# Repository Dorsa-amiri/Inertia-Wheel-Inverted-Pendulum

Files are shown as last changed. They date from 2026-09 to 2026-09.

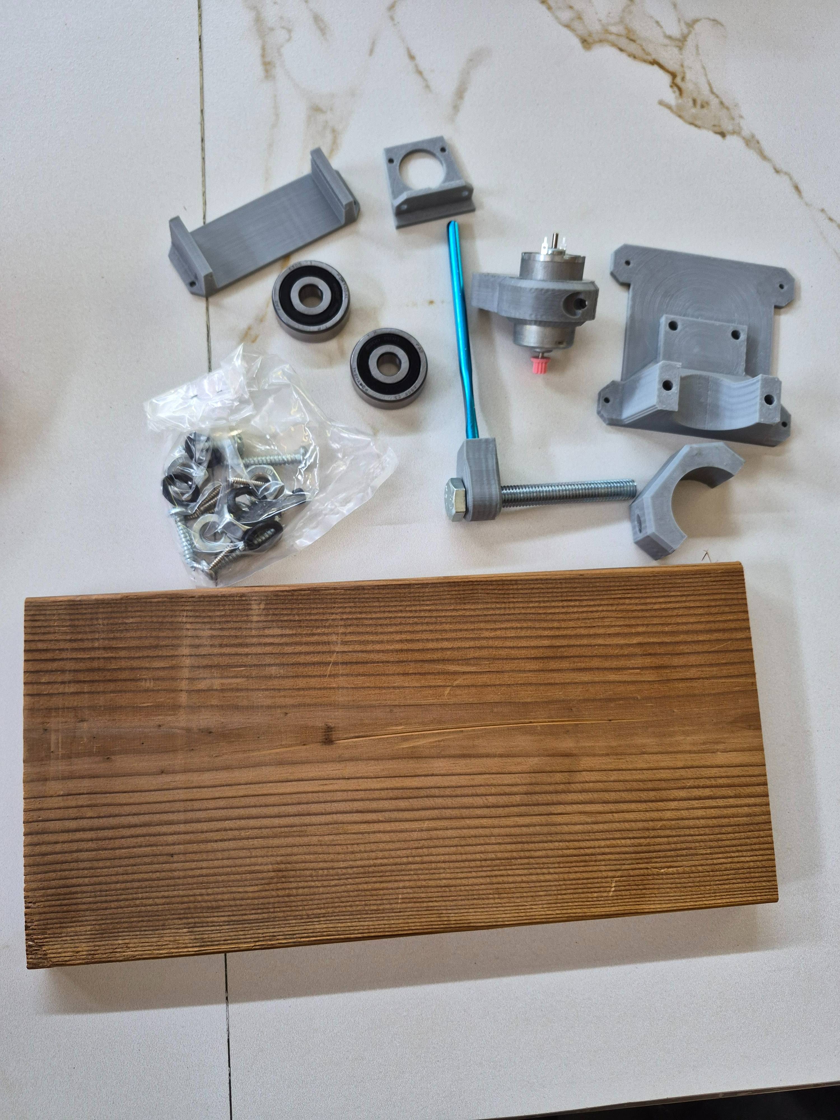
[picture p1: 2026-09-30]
Images/Components/20260816_130111_compressed.jpg

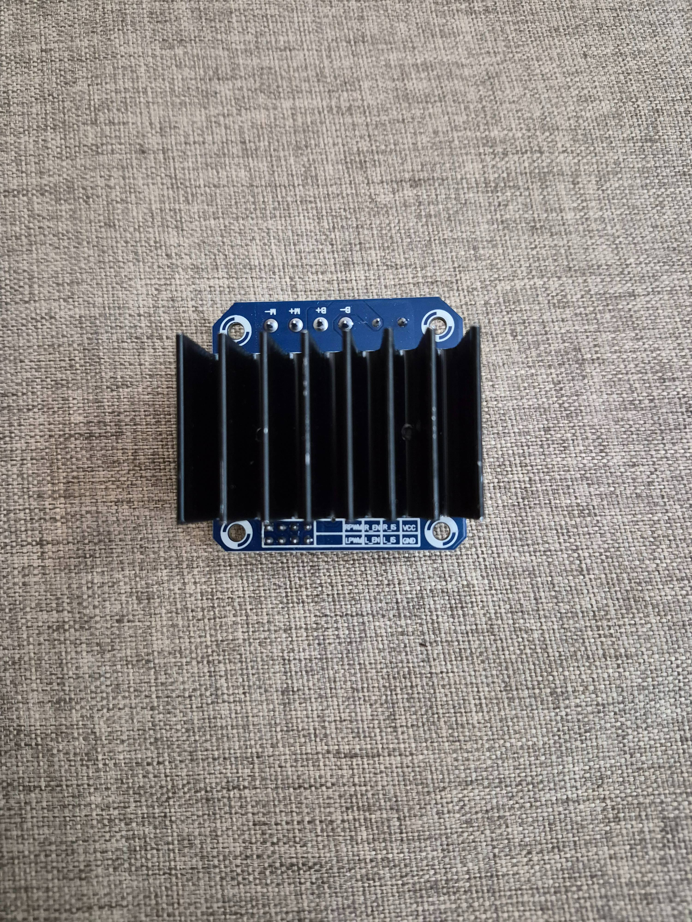
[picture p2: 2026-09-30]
Images/Components/20260811_233942_compressed.jpg

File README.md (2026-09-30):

# Inertia Wheel Inverted Pendulum

## Table of Contents
- [Project Overview](#project-overview)
- [Hardware](#hardware)
  - [Component List, Rationale & Datasheets](#component-list-rationale--datasheets)
  - [Where We Bought Everything](#where-we-bought-everything)
  - [3D Printing](#3d-printing)
  - [Assembly](#assembly)
- [Modeling & Control Design](#modeling--control-design) (coming soon)
- [Software](#software) (coming soon)
- [Component Testing](#component-testing)
- [Roadmap / Future Work](#roadmap--future-work)
- [Acknowledgements](#acknowledgements)

---

## Project Overview
Inertia Wheel Inverted Pendulum: System Overview & Control Scope

The Inertia Wheel Inverted Pendulum is an underactuated, non-linear dynamic system designed to demonstrate the real-time stabilization of an inherently unstable process. Unlike traditional cart-pole mechanisms that achieve equilibrium through base displacement, this platform balances vertically by using reaction torque generated at its free end. Accelerating a high-inertia flywheel mounted atop the pendulum rod produces equal and opposite rotational forces that continuously counteract destabilizing gravitational torques. To support physical realization, the platform integrates a complete hardware and software framework covering computer-aided mechanical design, embedded electronics, and low-latency real-time execution.

Mathematically, the platform bridges non-linear physical dynamics with state-space control theory. By linearizing the system's differential equations around the unstable upright equilibrium point, an optimal Linear Quadratic Regulator (LQR) is synthesized within MATLAB. Operating on full state feedback (continuously monitoring pendulum position, angular velocity, and flywheel speed), this real-time feedback loop establishes a baseline for stabilizing complex, underactuated hardware processes against external perturbations.

Building on this baseline of classical PD and LQR control, the project also aims to explore more advanced control strategies, including Model Predictive Control (MPC), sliding mode control, and adaptive methods, time permitting. Where implemented, these controllers would be benchmarked under identical operational conditions to examine trade-offs across dynamic response, disturbance rejection, energy efficiency, and algorithmic robustness.

---

## Hardware

This project builds on the mechanical structure and 3D-printed geometry of [askuric/inverted_inertia_pendulum](https://github.com/askuric/inverted_inertia_pendulum), which we kept unchanged, but departs from it substantially elsewhere. Several years have passed since the original project was published, and a number of the originally suggested electronic components (in particular the salvaged Mabuchi RS-385PH motor with factory-fitted encoder, and the Monster Moto Shield driver) are no longer realistically available to us; nearly all electronic components were re-selected and updated as a result. The project also implements and compares several different controllers (see [Modeling & Control Design](#modeling--control-design)), going well beyond the original's scope. This section documents every hardware component we used, why we chose it, and where to find more information or buy it. Photos of the physical parts we bought are collected in [`/images/hardware/`](./images/hardware/); a condensed purchase list with links and prices is kept in [`/docs/BOM.md`](./docs/BOM.md).

### Component List, Rationale & Datasheets

#### Microcontroller: STM32F411CEU6 ("Black Pill" board, WeAct Studio)
The microcontroller is the central processing unit of the system: it reads sensor data, executes the control algorithm, and commands the motor driver.
- Core: ARM Cortex-M4 with hardware FPU, up to 100 MHz
- Memory: 512 KB Flash, 128 KB RAM
- Hardware timers with quadrature encoder decoding mode, PWM output, and I²C peripheral, everything the control loop needs
- Datasheet: [STM32F411xC/E, STMicroelectronics](https://www.st.com/resource/en/datasheet/stm32f411ce.pdf)
- Product page: [st.com](https://www.st.com/en/microcontrollers-microprocessors/stm32f411ce.html)
- Board reference: [WeAct Black Pill V2.0, STM32-base project](https://stm32-base.org/boards/STM32F411CEU6-WeAct-Black-Pill-V2.0.html)

We replaced the original project's official Nucleo-F411RE board with a much cheaper "Black Pill" development board built around the same MCU. It exposes the same core peripherals needed for this project. The one practical difference is that the Black Pill has no onboard ST-Link debug probe; firmware is instead flashed through the chip's built-in USB DFU bootloader over the onboard USB Type-C port, using STM32CubeProgrammer instead of a one-click Keil download. Live SWD debugging (breakpoints) is not available this way; an external ST-Link can be added later if needed.

> Note: the Black Pill's 25 MHz crystal cannot be divided to the precise 48 MHz required by the USB peripheral while the core runs at its rated maximum of 100 MHz; with USB (and therefore the DFU bootloader) enabled, the achievable core clock is capped at 96 MHz. This project runs at 96 MHz for that reason.

> Caution: on this board, the +5V header pins are wired directly to the USB connector's VBUS with no protection diode. Do not power the board from an external supply and USB at the same time.

#### Motor Driver: BTS7960 (43 A dual half-bridge module)

- Datasheet: [BTS7960, Infineon Technologies](https://www.infineon.com/assets/row/public/documents/10/57/infineon-bts7960-ds-en.pdf)
- Supply voltage range: 5.5 to 27.5 V, up to 43 A continuous
- Built-in protection: overcurrent, overtemperature, short-circuit, undervoltage lockout

The original project used a Monster Moto Shield (VNH2SP30-based), an Arduino-shield-form-factor product that is largely discontinued and hard to source today. BTS7960 modules are a widely available, inexpensive, well-documented alternative that comfortably exceeds this project's current requirements, giving a generous safety margin over the motor's actual draw.

#### Motor: Mabuchi RS-385, 12 V, dual-shaft, gearless

"RS-385" is a standard small DC motor frame size, produced by Mabuchi (among other manufacturers) in several variants. We specifically required:
- Dual shaft, because the design uses both ends: the front shaft drives the inertia wheel, the rear (free) shaft carries the speed-feedback sensor
- No gearbox, because gear backlash introduces nonlinear, hard-to-model behavior that is undesirable for precise control, and because the reduced output speed of a gearmotor is unsuitable for a reaction wheel that needs to spin up and down quickly

The original repository used a salvaged Mabuchi RS-385PH pulled from office equipment (printers/copiers), which came with a factory-fitted encoder; these units are essentially unobtainable today. We sourced a new (not salvaged) Mabuchi RS-385 motor without the factory encoder, and paired it with a separately purchased AS5600 sensor for speed feedback (see below).

- Voltage: 12 V
- Shaft diameter: 2.3 mm, dual-shaft, gearless
- Codes printed on the motor housing: `6007-350-0018`, `385-17150-01`, `1H7G`

No public datasheet could be located for this exact part number; the codes above appear to be an internal packager/distributor part number rather than a standard Mabuchi catalog designation, so the figures listed here are limited to what is printed on the unit itself. For general reference on this motor family's typical electrical characteristics, see the [Mabuchi RS-385PH datasheet](https://datasheet.octopart.com/RS385PH-10280-Mabuchi-datasheet-13546593.pdf). Note that this is a different, encoder-equipped variant, so its figures should not be taken as exact for our unit.

#### Motor Speed Sensor: AS5600 magnetic rotary position sensor

- Datasheet: [AS5600, ams AG](https://files.seeedstudio.com/wiki/Grove-12-bit-Magnetic-Rotary-Position-Sensor-AS5600/res/Magnetic%20Rotary%20Position%20Sensor%20AS5600%20Datasheet.pdf)
- Product page: [ams-osram.com](https://ams-osram.com/products/sensor-solutions/position-sensors/ams-as5600-position-sensor)
- 12-bit resolution (4096 counts/revolution), contactless Hall-effect sensing, I²C output

The original project measured motor speed with a hand-built sensor: two discrete digital Hall sensors plus a small multi-pole magnetic disc salvaged from a Pololu Romi encoder kit, requiring careful manual alignment. We replaced this with a single AS5600 module (magnet included), mounted opposite a small magnet glued to the motor's rear shaft. This is mechanically much simpler to install and gives substantially higher resolution than the original 12 to 20 CPR approach.

Because a generic gearless RS-385 motor does not have the small internal-spline gear that the original inertia wheel STL's hub is shaped for, we designed and 3D-printed a small custom coupler that mates the wheel's original 12-tooth internal spline (measured directly from the STL geometry) to a plain round motor shaft. See [`/CAD/STL/motor_shaft_to_wheel_adapter_12T.stl`](./CAD/STL/motor_shaft_to_wheel_adapter_12T.stl).

#### Pendulum Angle Sensor: two-phase optical rotary encoder, 600 CPR (labeled E6A2-38F600-12C-2M)
This sensor is the primary feedback signal of the whole system: it measures the pendulum arm's angle relative to vertical, the variable the controller is trying to stabilize.

- Source: [Partineh](https://partineh.com/product/%d8%b1%d9%88%d8%aa%d8%a7%d8%b1%db%8c-%d8%a7%d9%86%da%a9%d9%88%d8%af%d8%b1-%d9%86%d9%88%d8%b1%db%8c-%d8%af%d9%88-%d9%81%d8%a7%d8%b2-600-%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) (6–24 VDC, 38 mm body diameter, 6 mm shaft, 600 pulses/rev, up to 5000 RPM)

The part is stamped `E6A2-38F600-12C-2M`, styled after Omron's E6A2 series naming, but its specifications (38 mm body, 600 PPR) do not match any genuine Omron E6A2 model (which tops out at 25 mm body diameter and 500 PPR). It appears to be an unofficial part following that naming convention rather than a genuine Omron part, and no datasheet matching its actual specifications could be located; the figures above come from the seller's listing.

We chose a digital two-phase (quadrature) optical encoder over a potentiometer for several reasons:

- Precision for the controller. The higher the precision of the pendulum angle measurement, the better a controller, especially LQR, can manage the unstable equilibrium. This need for precision is what ruled out a potentiometer in the first place.
- Prior experience with potentiometers. From earlier work with precision potentiometers, we knew that because the pendulum's rotation is not confined to a small range (it can exceed 360°) while the highest precision is only needed near the small angular range around vertical, a multi-turn (10-turn) potentiometer only exercises a small portion of its resistive track within that critical range. This makes the signal noise-sensitive, particularly with the Chinese-made unit we would have used; German-made precision potentiometers reportedly avoid this issue, but their price was significantly higher than we could justify (this was not a low-cost part in absolute terms, just cheaper than the German alternative).
- Noise immunity. A digital two-phase output is inherently more noise-resistant than an analog potentiometer signal.
- Direction sensing. The AB output (two phases, 90° apart) reports rotation direction in addition to magnitude, something a simple potentiometer does not provide by default.
- Effective resolution above the nominal rating. Counting both rising and falling edges on both phases yields up to 4x the nominal resolution, so even a 360 CPR version would effectively give around 1440 counts/revolution. This is why lower-CPR options were also viable candidates. We chose the 600 CPR version as the best, most precise option available (2400 effective counts/revolution versus 1440 for the 360 CPR version).
- Physical compatibility. The body diameter and shaft size of this encoder (38 mm body, 6 mm shaft) match the original project's `encoder_holder.STL` and `axel_adapter_10mm_encoder.STL` print files directly, requiring no redesign.

> Note: Pull-up resistors (1 to 10 kΩ) are required on both phase lines to VCC. Without them the encoder output is unusable and can potentially damage the sensor's output stage.

#### Power Supply: 18 V, 3 A switching adapter (Lexus IR-54)
Feeds the motor side of the BTS7960 driver only (logic-side components run off the MCU board's own 5 V/3.3 V rails). Input: AC 100–240 V, 50/60 Hz; output: 18 V, 3 A. Since the motor's rated voltage (12 V) is lower than the supply, the maximum PWM duty cycle is capped in firmware (around 65 to 70%) so the motor's effective voltage never exceeds its rating. 3 A gives comfortable headroom over this small motor's actual draw.

#### Mechanical Hardware

| Part | Spec |
|---|---|
| Pendulum arm rod | Aluminum, solid, ⌀6 mm × 120 mm (repurposed from a crochet hook) |
| Pivot bolt + nuts | M10×1.5 bolt (1×), M10×1.5 nuts (3×) |
| Fasteners | M3 socket-head screws, assorted lengths (8 to 16 mm) |
| Heat-set threaded inserts | Brass, M3 |
| Pivot bearings | 6300-series ball bearings (10 × 35 × 11 mm), 2× |
| Base plate | Wooden board, 20 × 140 × 300 mm |

These were kept as specified in the original project, since they are standard, widely available parts.

### Where We Bought Everything

Most components were purchased in person rather than online, because no single supplier reliably stocked more than one or two of the parts at a time; each component was typically found at a different store. Two components were ordered online instead: the pendulum-angle encoder ([partineh.com](https://partineh.com/product/%d8%b1%d9%88%d8%aa%d8%a7%d8%b1%db%8c-%d8%a7%d9%86%da%a9%d9%88%d8%af%d8%b1-%d9%86%d9%88%d8%b1%db%8c-%d8%af%d9%88-%d9%81%d8%a7%d8%b2-600-%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)) and the pivot bearings ([fidarbearing.ir](http://fidarbearing.ir)). Supplier websites for the remaining, in-person-purchased parts are still listed in [`/docs/BOM.md`](./docs/BOM.md) for reference and stock-checking.

Components that were genuinely hard to find: the Monster Moto Shield (discontinued, replaced with BTS7960), a factory-encoder-equipped RS-385PH motor (essentially unobtainable, replaced with a bare motor plus AS5600), and consistent stock of the pendulum's optical rotary encoder across suppliers.

### 3D Printing

All parts were printed in PLA. Printer used: *(insert printer/slicer details)*. Minimum layer height available to us was 0.2 mm; the original repository recommends 0.1 mm specifically for the inertia wheel for best surface finish, which we adjusted for accordingly (see notes below).

All files below live under [`/CAD/STL/`](./CAD/STL/). Slicer screenshots documenting these settings are in [`/images/printing/`](./images/printing/).

| # | File | Layer height | Infill |
|---|---|---|---|
| 1 | `mabuchi_wheel_12T.STL` | 0.2 mm | 50%+ |
| 2 | `motor_mout_mabuchi.STL` | 0.2 mm | 30% |
| 3 | `bearing_holder.STL` | 0.2 mm | 30% |
| 4 | `mount_table_sharft_holder.STL` | 0.2 mm | 30% |
| 5 | `table_mount.STL` | 0.2 mm | 30% |
| 6 | `nucleo_holder.STL` | 0.2 mm | 30% |
| 7 | `encoder_holder.STL` | 0.2 mm | 30% |
| 8 | `axel_adapter_10mm_encoder.STL` | 0.2 mm | 100%* |
| 9 | `motor_shaft_to_wheel_adapter_12T.stl` (custom, this repo) | 0.2 mm | 100% |

Original Solidworks/STEP source files are kept in [`/CAD/source/`](./CAD/source/).

\* Small parts with thin cross-sections are automatically printed fully solid by the slicer regardless of the configured infill percentage, since there is no room for a distinct infill pattern. This is expected behavior and does not indicate a problem; it only increases strength.

Only the `mabuchi_wheel_12T.STL` variant is used (not the 14-tooth version), since the custom motor-shaft adapter was designed specifically to match its internal spline geometry.

### Assembly

*(Step-by-step assembly instructions to be written here: pivot/base assembly, pendulum arm, motor + wheel + encoder at the free end, pendulum-angle encoder at the pivot, electronics mounting, wiring. Reference photos go in [`/images/assembly/`](./images/assembly/).)*

---

## Component Testing

1-STM32F411CEU6 Board Test

To verify that the STM32F411CEU6 development board was functioning correctly, we performed a basic GPIO test by turning the onboard LED on and off.
The test code can be found here:
[Inertia Wheel Inverted Pendulum – GitHub](https://github.com/Dorsa-amiri/Inertia-Wheel-Inverted-Pendulum)

2-driver

---

## Modeling & Control Design
*Coming soon: dynamic model, simulation, and initial controller gain computation (PD, LQR).*

## Software
*Coming soon: firmware, hardware validation/test routines, controller implementation.*

## Roadmap / Future Work

- [ ] Control the system using image processing as an alternative sensing method
- [ ] Graphical interface with buttons to select and run a given controller
- [ ] A dedicated test/diagnostic mode: automatically return the system to its home position before running, verify each subsystem responds correctly to known commands, and gracefully handle faults (e.g. out-of-range encoder readings, a motor spinning without responding to commands, a lost communication link) instead of producing undefined/garbage output
- [ ] Compare simulation results against real system results for each controller, and compare all controllers against each other

## Acknowledgements

Based on [askuric/inverted_inertia_pendulum](https://github.com/askuric/inverted_inertia_pendulum). Mechanical design and 3D-printed geometry are used largely unmodified; electronic components were updated where the originals were no longer available.

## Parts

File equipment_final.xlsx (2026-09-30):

 | Name | Amount | In person | Total Cost | Delivery cost | Website
Electrical | Nucleo STM32F411RE |  |  | 44380000 |  | https://bir-robotic.ir
 | STM32F411CEU6 BlackPill Development Board | 1 |  | 6400000 |  | -
 | BTS7960 Pwm Motor Driver 43A6-27V | 1 |  | 8150000 |  | www.belelectronic.com www.iran-module.ir
 | RS-385 motor | 1 |  | 3000000 |  | www.mechanicaal.ir
 | AS5600 Magnetic Encoder | 1 |  | 1950000 |  | -
 | HN3806-AB-600N | 1 |  | 27400000 | 2000000 | www.partineh.com
 | Power Adapter 18V-3A | 1 |  | 6000000 |  | www.iranadaptor.ir
 | 2 Pin Euro Plug | 1 |  | 500000 |  | www.iranadaptor.ir
Mechanical | Aluminum rod, ⌀6mm, solid (repurposed from a solid crochet hook, straightened) | 1 |  | 550000
 | M3 Brass Heat-Set Threaded Insert | 4 |  | 440000
 | FAG 6300.2RSR.C3 Radial Ball Bearing | 2 |  | 10000000 | 2360000 | www.fidarbearing.ir
 | Screws (4 screws for the brass inserts + 1 screw for fixing the motor + 1 M10x1.5 screw, length 130-140 mm, + 3 M10x1.5 nuts (if lower-profile nuts are available, the screw length can be reduced accordingly so it doesn't protrude) + 6 self-tapping screws for attaching the assembly to the base board + 3 screws for connecting the encoder mount to the base) |  |  | 800000
 | Wooden board, 2×14×30 cm | 1 |  | free
3D Print PLA |  |  |  | 15000000 | - | -
 |  |  |  | 84550000 | IRR

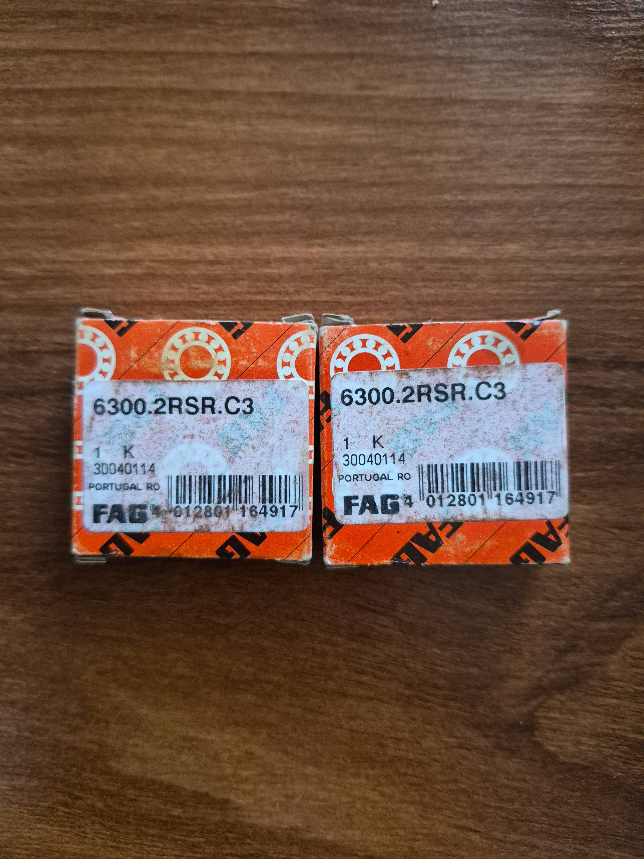
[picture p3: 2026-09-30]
Images/Components/20260816_104652_compressed.jpg

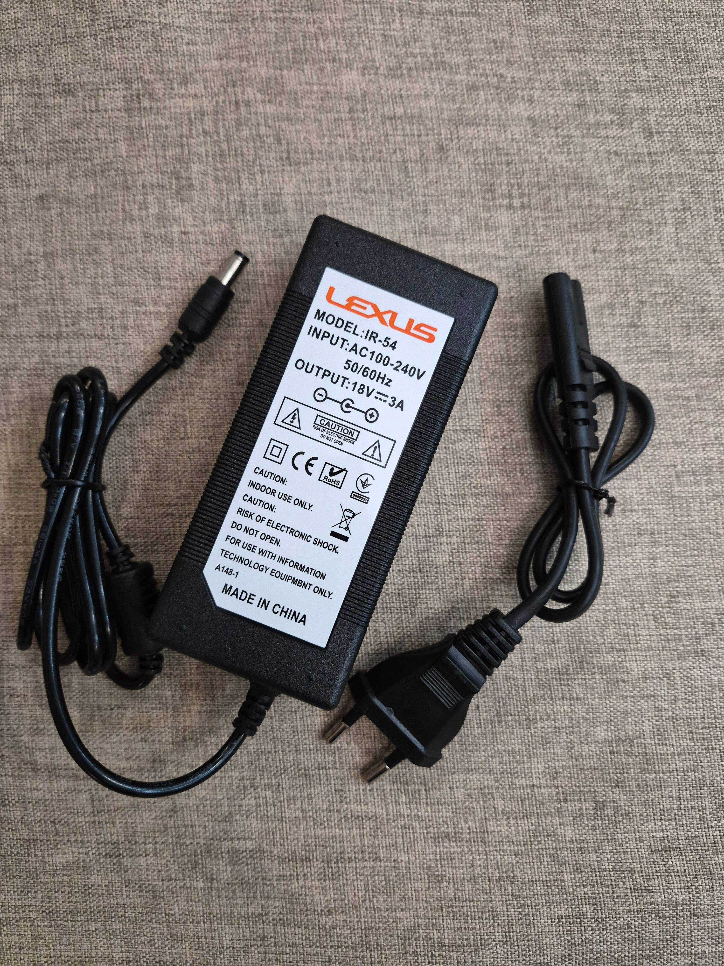
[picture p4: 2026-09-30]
Images/Components/20260811_233817_compressed.jpg

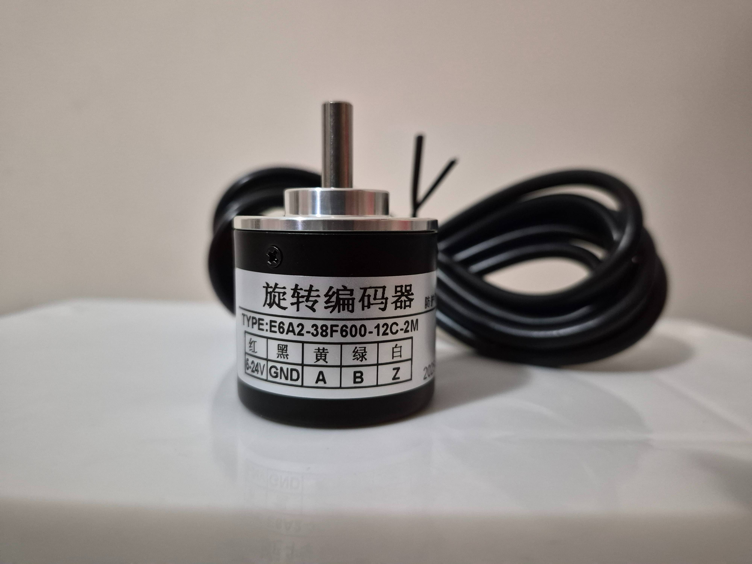
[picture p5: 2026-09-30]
Images/Components/20260815_205754_compressed.jpg

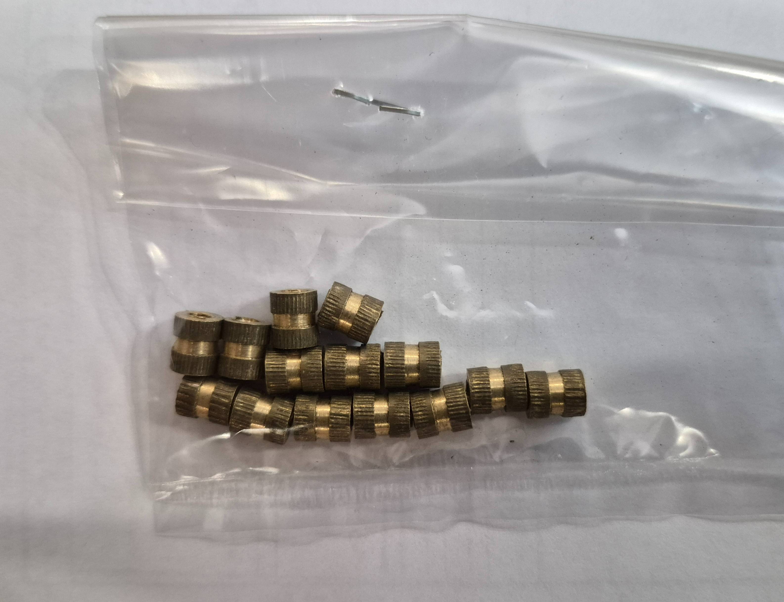
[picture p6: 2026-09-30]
Images/Components/20260811_234137_compressed.jpg

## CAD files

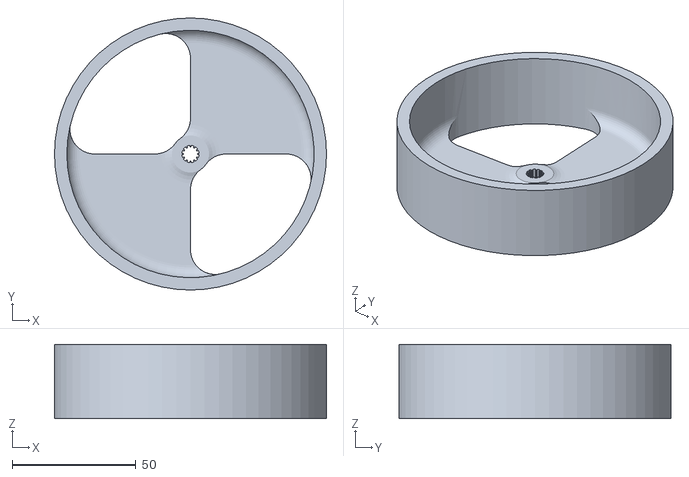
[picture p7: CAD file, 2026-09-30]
STL/mabuchi_wheel_12T.STL
110.0 x 110.0 x 30.0

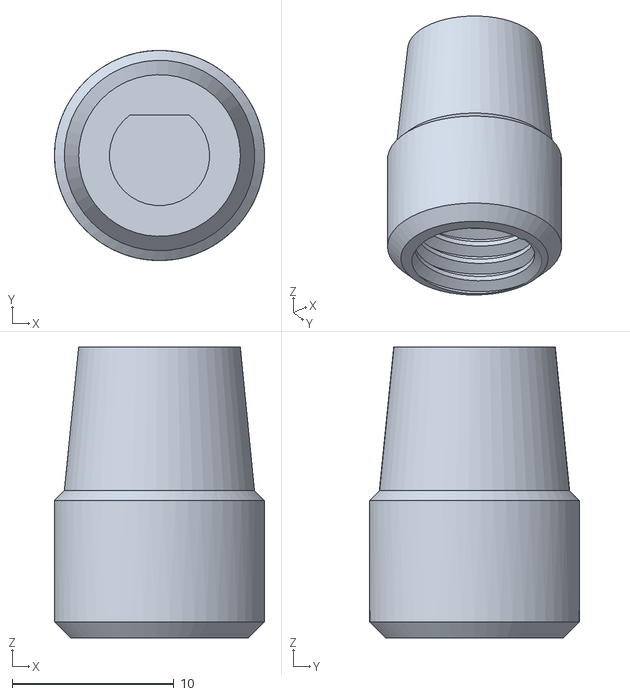
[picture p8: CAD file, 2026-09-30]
STL/axel_adapter_10mm_encoder.STL
13.0 x 13.0 x 18.0

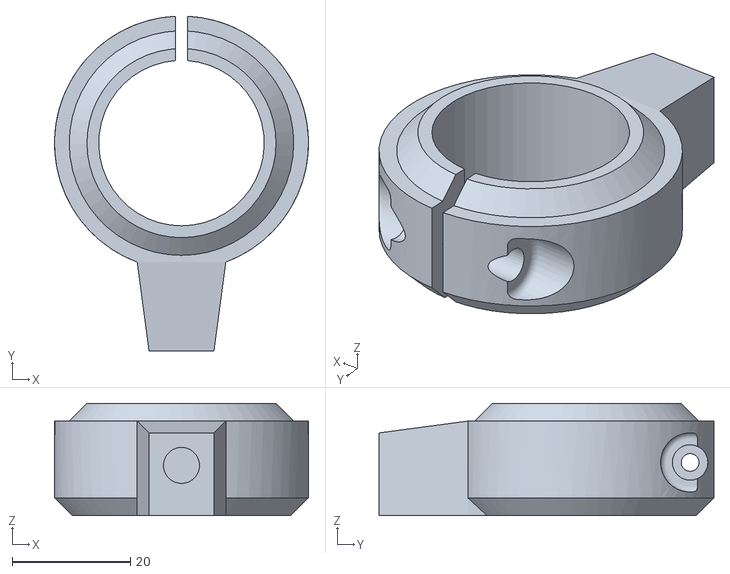
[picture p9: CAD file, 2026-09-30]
STL/motor_mout_mabuchi.STL
43.0 x 56.6 x 19.0

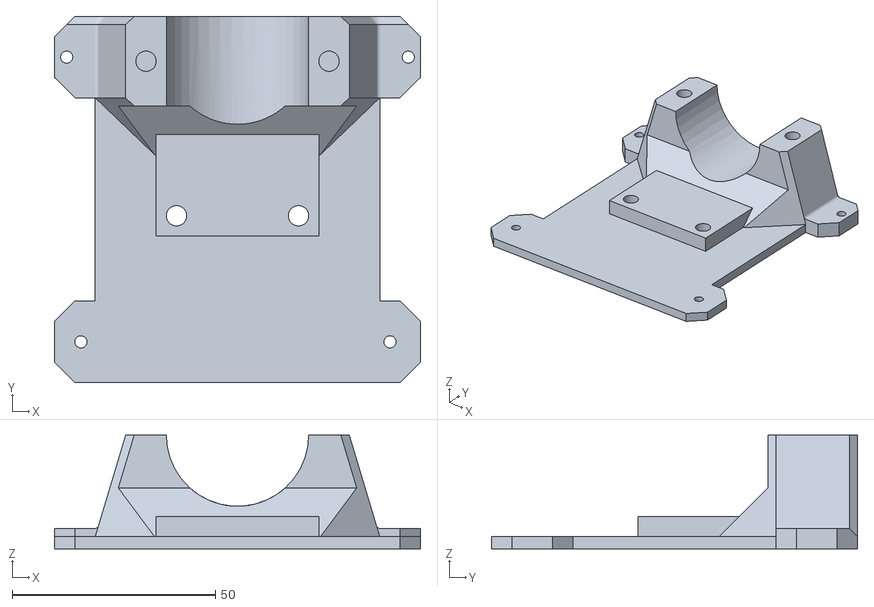
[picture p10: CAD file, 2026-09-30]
STL/table_mount.STL
90.0 x 90.0 x 28.0

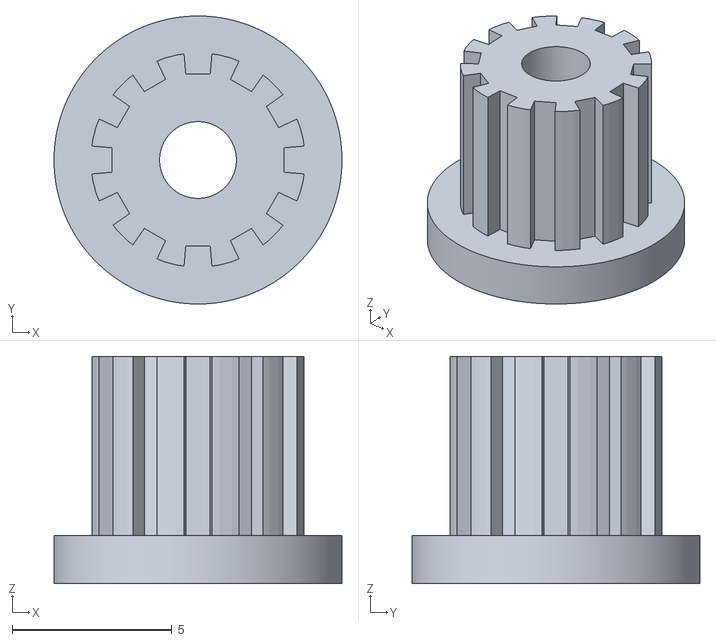
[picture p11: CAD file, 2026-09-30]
STL/motor_shaft_to_wheel_adapter_12T.stl
9.00 x 9.00 x 7.10

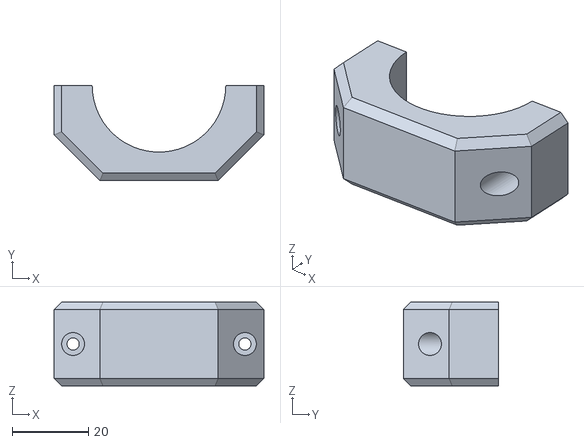
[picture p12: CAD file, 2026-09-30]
STL/bearing_holder.STL
55.0 x 25.0 x 22.0

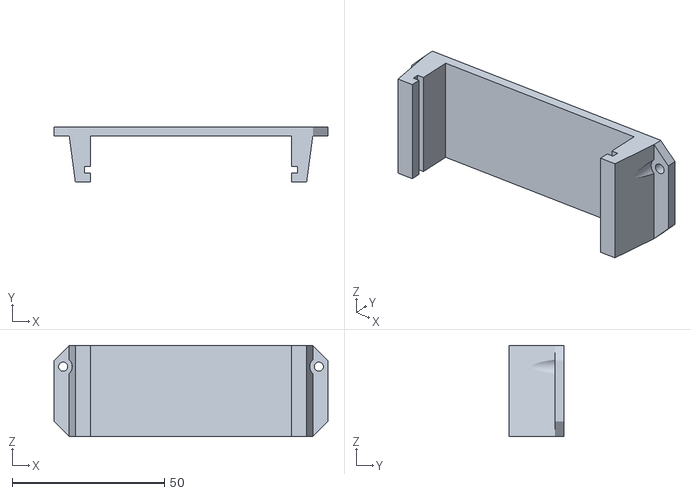
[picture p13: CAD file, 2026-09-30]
STL/nucleo_holder.STL
90.0 x 18.0 x 30.0

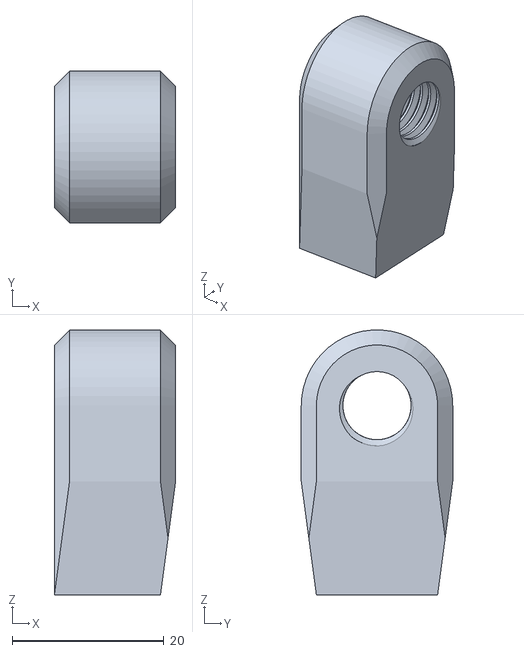
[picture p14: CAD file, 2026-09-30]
STL/mount_table_sharft_holder.STL
16.0 x 20.0 x 35.0

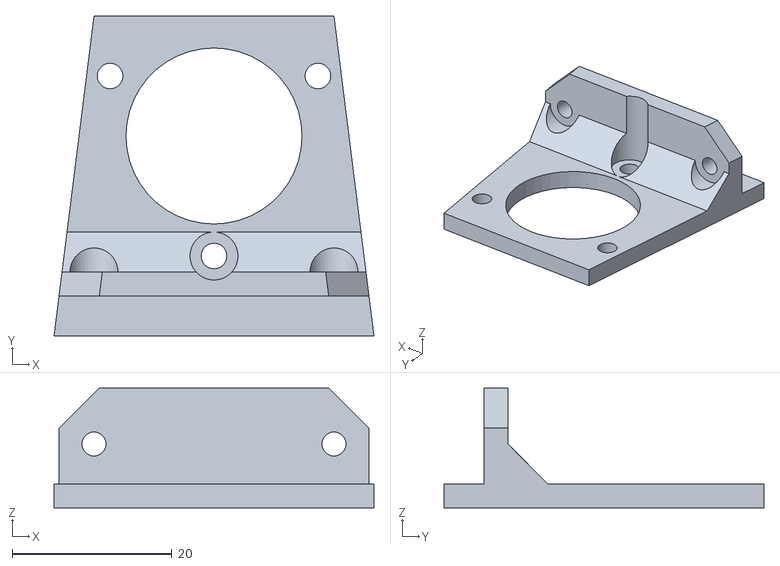
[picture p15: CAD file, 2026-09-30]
STL/encoder_holder.STL
40.0 x 40.0 x 15.0

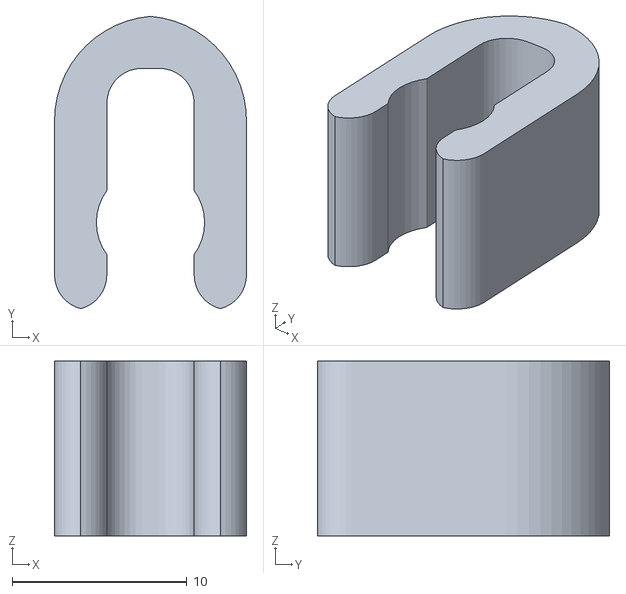
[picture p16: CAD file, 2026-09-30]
STL/cable_holder(Optional).STL
11.0 x 16.7 x 10.0

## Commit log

2026-08-13 Revise README with project details and updates
    Expanded the README to include detailed project overview, hardware components, assembly instructions, and future work roadmap.
2026-08-13 Update README with Black Pill board details and cautions
    Added board reference and notes about the Black Pill's limitations and cautions regarding power supply.
2026-08-13 Clarify motor details and sourcing in README
    Updated motor description to specify the manufacturer and changes in sourcing.
2026-08-13 Update motor specifications in README
    Added specifications and sourcing information for the Mabuchi RS-385 motor.
2026-08-23 Initial STM32 project
2026-09-30 Move STM32 project to Codes/First Tests/Black_Pill_Test
2026-09-30 Update project
    [axel_adapter_10mm_encoder.STL, bearing_holder.STL, cable_holder(Optional).STL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]
